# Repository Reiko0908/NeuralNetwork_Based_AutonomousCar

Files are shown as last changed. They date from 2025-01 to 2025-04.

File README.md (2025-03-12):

# NeuralNetwork_Based_AutonomousCar

## Project Overview
This project focuses on developing an autonomous car system powered by neural networks (NN). Inspired by the design architecture of micromouse, the car is designed to navigate autonomously using deep learning techniques. The project leverages deep learning and neural network models to enable the autonomous functionalities of the car. The neural network processes real-world sensor data to make real-time decisions for the car's navigation. The project timeline is divided into several stages:
1. **Concept Development**: Initial phase where the concept was developed.
2. **Gamepad PCB Design**: Creation of the gamepad hardware to control the car.
3. **Autonomous Car Design**: Currently in progress, focusing on the car's hardware and software integration.
4. **Neural Network Training**: Future phase where the model will be trained.
5. **Documentation**: Final phase to document the project.

## Software Architecture
- **Data Collection**: Using the gamepad (now replaced by computer control) to navigate the car in a physical map with walls. The sensors collect data and transmit it to the ESP32-S3 on the computer.
- **Machine Learning Training**: Utilizing Python and TensorFlow to train the neural network model.
- **Deployment**: Importing the trained model configurations to the car for autonomous navigation.

## Hardware

### Car Hardware
- **ESP32-S3 Super Mini**: Main microcontroller used in the car.
- **GY87 9-DOF IMU**: Inertial measurement unit for orientation and motion sensing.
- **5 VL53L0X Sensors**: Distance measurement sensors for mapping the environment.
- **L293DD Motor Driver**: Controls the motors of the car.
- **GA12 N20 Motor**: Motor with a step-up gearbox of 56:16 for movement.
- **2S Lipo Battery**

### Gamepad Hardware
- **Joysticks**
- **MPU6050 6-DOF IMU**
- **ESP32-S3 N16R8**
- **ST7789 LCD TFT SPI Screen**
- **IP5306 for Power Management**
- **Low Profile Switches**
- **Single-cell 18650 Battery**
- **Additional Buttons and Pin Headers**

## Machine Learning Training Procedure
1. **Collecting Data**: Create a physical map with walls and use the gamepad (now our computer) to control the car. The 5 VL53L0X sensors onboard will collect map data, transmit them to the ESP on the computer.
2. **Training the Model**: Use Python with TensorFlow library to train the neural network model.
3. **Deployment**: Import the trained model configurations to the car and let it navigate autonomously.

### Milestone Pictures
- **Micromouse Design Inspiration**
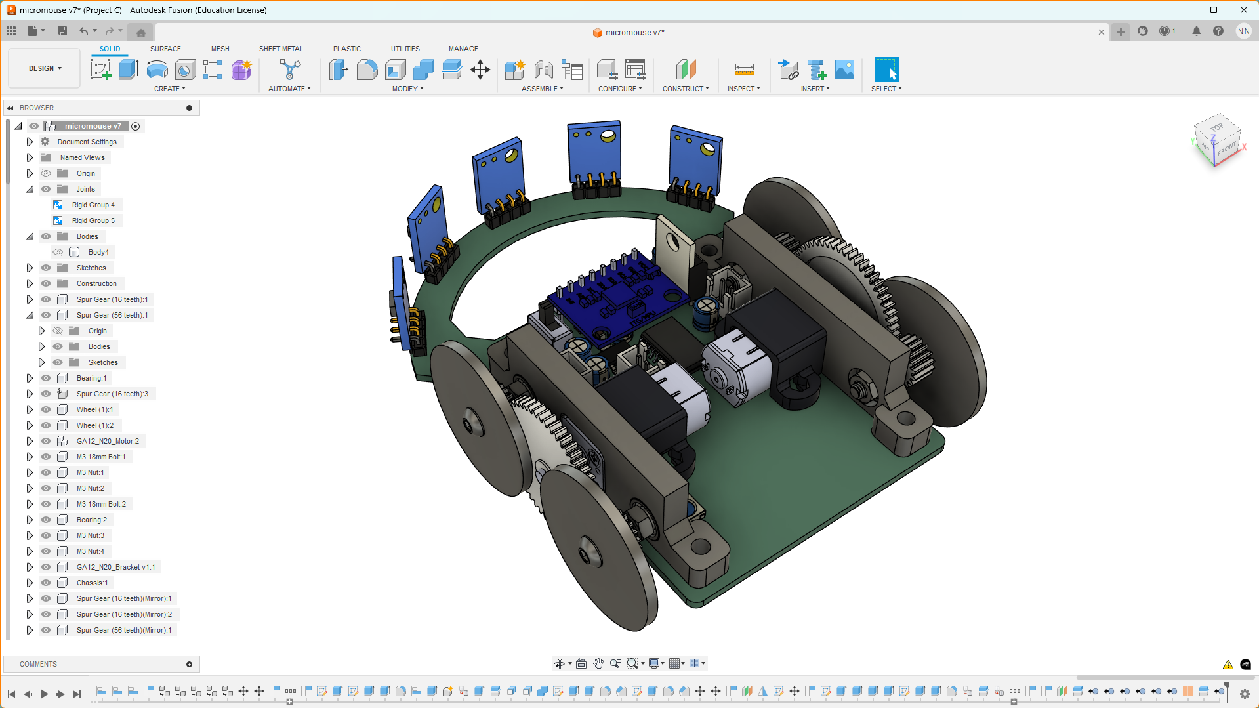
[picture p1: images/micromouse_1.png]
Micromouse 1
  
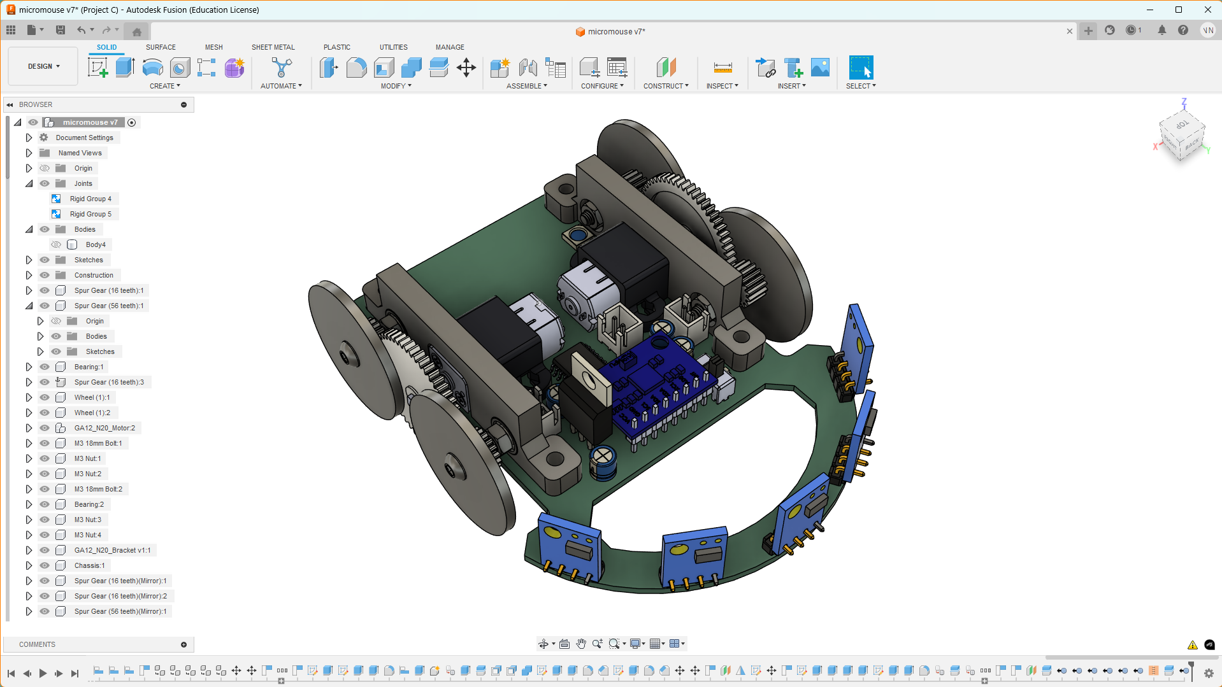
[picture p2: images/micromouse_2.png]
Micromouse 2
  
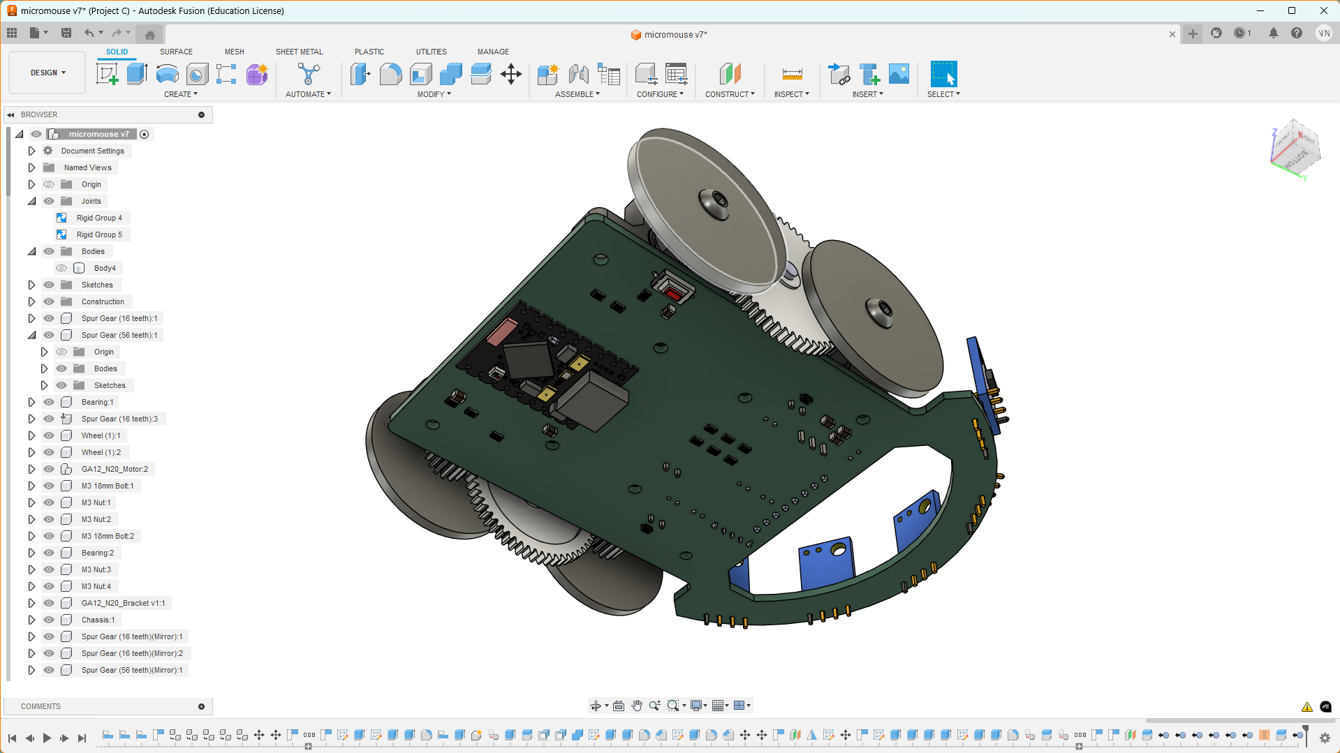
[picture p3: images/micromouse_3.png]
Micromouse 3
  
- **Gamepad PCB**
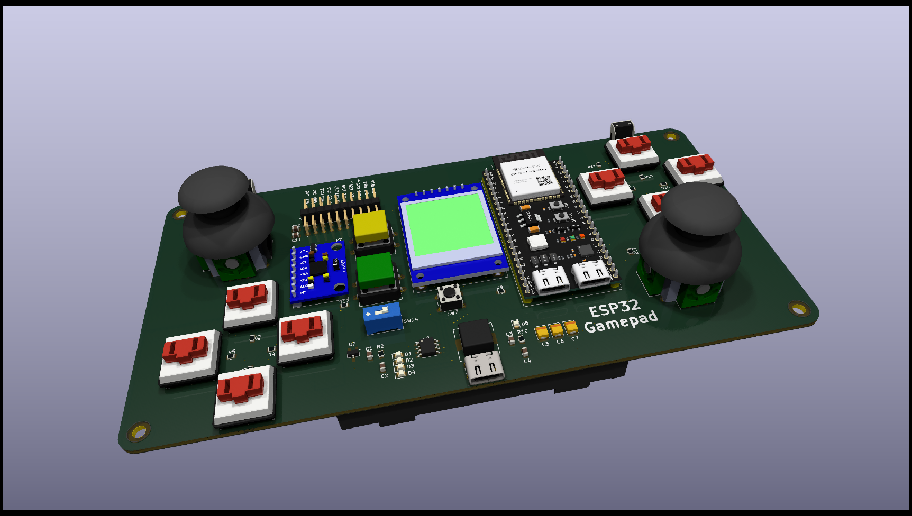
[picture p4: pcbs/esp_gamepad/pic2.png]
Gamepad Pic 2
  
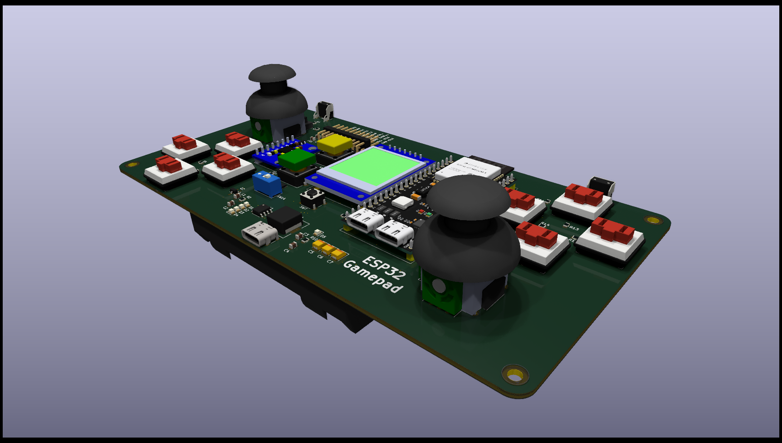
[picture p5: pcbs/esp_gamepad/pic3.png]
Gamepad Pic 3
  
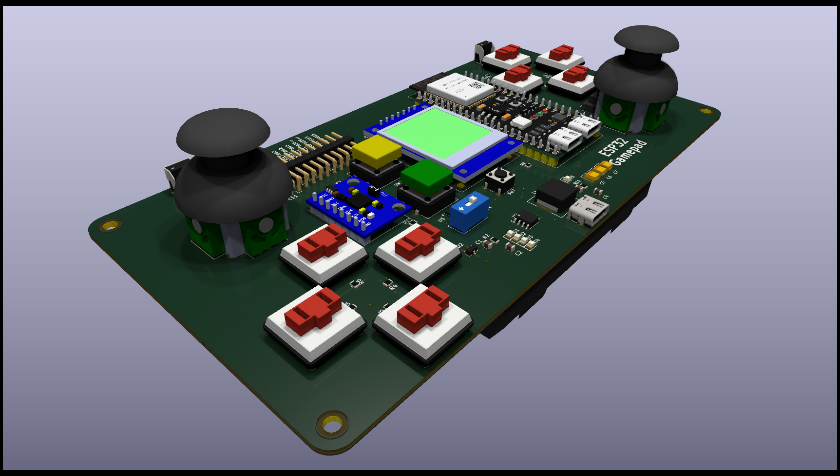
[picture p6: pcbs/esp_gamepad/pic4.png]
Gamepad Pic 4
  
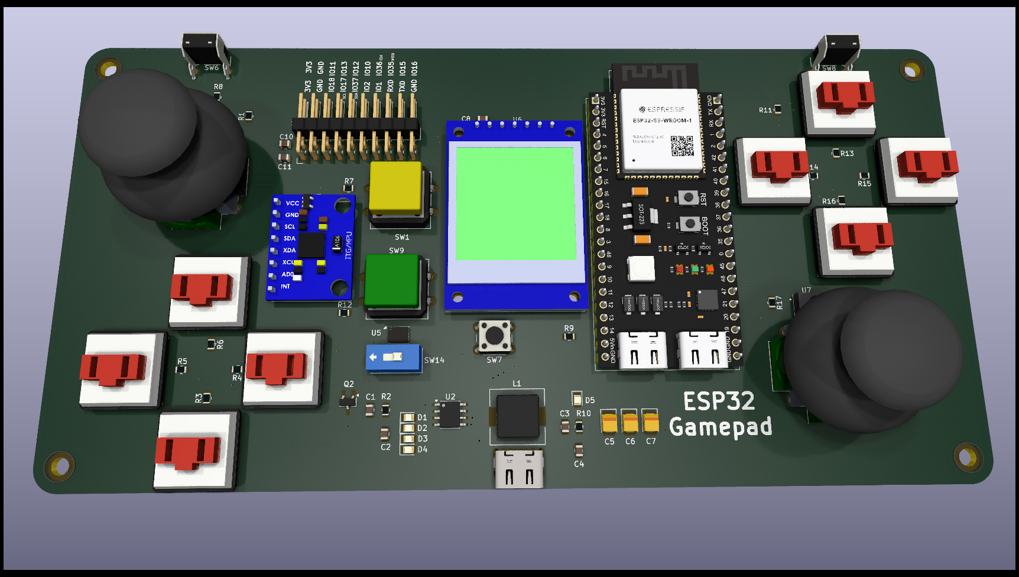
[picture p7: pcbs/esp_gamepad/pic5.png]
Gamepad Pic 5
  

## Additional Information
The gamepad PCB encountered a hardware issue that cannot be fixed in time. As a workaround, we will use an external ESP32-S3 connected to the computer to control the car via BLE. We will continue to develop and improve the project.

---

*Author: pacman314159*

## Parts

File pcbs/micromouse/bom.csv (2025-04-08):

Reference | Value | Datasheet | Footprint | Qty | DNP
BT1 | Lipo 2S | ~ | XH_2p54:2P_male | 1
C1,C2 | 100uF | ~ | Capacitor_SMD:C_0805_2012Metric_Pad1.18x1.45mm_HandSolder | 2
C3,C4,C8,C9,C14,C15 | 0.1uF | ~ | -- mixed values -- | 6
C5,C6,C7,C10,C11,C16,C17 | 10uF | ~ | -- mixed values -- | 7
C12,C13 | 470nF | ~ | Capacitor_THT:CP_Radial_D5.0mm_P2.00mm | 2
D1 | LED | ~ | LED_SMD:LED_0805_2012Metric_Pad1.15x1.40mm_HandSolder | 1
D2,D4 | 1N5819 | http://www.vishay.com/docs/88525/1n5817.pdf | Diode_SMD:D_SOD-323F | 2
D3 | WS2812B | https://cdn-shop.adafruit.com/datasheets/WS2812B.pdf | LED_SMD:LED_WS2812B_PLCC4_5.0x5.0mm_P3.2mm | 1
M1,M2 | GA12_N20 | ~ | XH_2p54:2P_male | 2
R1 | R | ~ | Resistor_SMD:R_0805_2012Metric_Pad1.20x1.40mm_HandSolder | 1
R2,R4,R5,R6,R7,R8,R9,R10,R11,R12,R13 | 10K | ~ | Resistor_SMD:R_0805_2012Metric_Pad1.20x1.40mm_HandSolder | 11
R3 | 6K2 | ~ | Resistor_SMD:R_0805_2012Metric_Pad1.20x1.40mm_HandSolder | 1
SW1 | SW_DPDT_x2 | ~ | SW_SS12D07VG4:SW_SS12D07VG4 | 1
SW2 | SW_Push | ~ | Button_Switch_SMD:SW_SPST_CK_RS282G05A3 | 1
U1,U4,U5,U6,U7,U8,U9,U10 | ~ |  | -- mixed values -- | 8
U2 | L7806 | http://www.st.com/content/ccc/resource/technical/document/datasheet/41/4f/b3/b0/12/d4/47/88/CD00000444.pdf/files/CD00000444.pdf/jcr:content/translations/en.CD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 | Package_TO_SOT_THT:TO-220-3_Vertical | 1
U3 | AMS1117-5.0 | http://www.advanced-monolithic.com/pdf/ds1117.pdf | Package_TO_SOT_SMD:SOT-223-3_TabPin2 | 1

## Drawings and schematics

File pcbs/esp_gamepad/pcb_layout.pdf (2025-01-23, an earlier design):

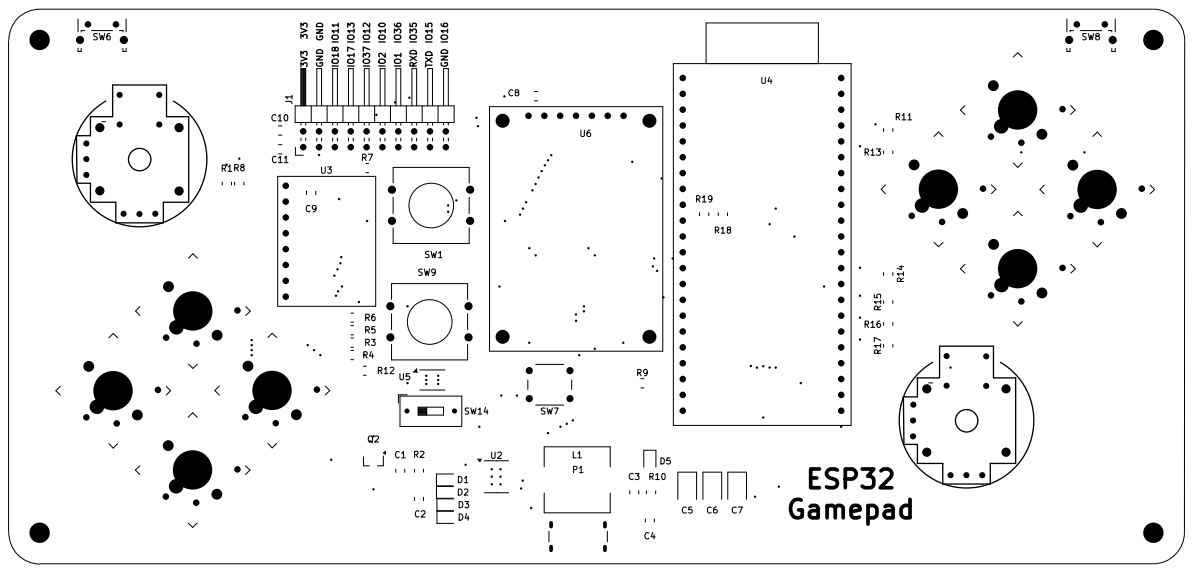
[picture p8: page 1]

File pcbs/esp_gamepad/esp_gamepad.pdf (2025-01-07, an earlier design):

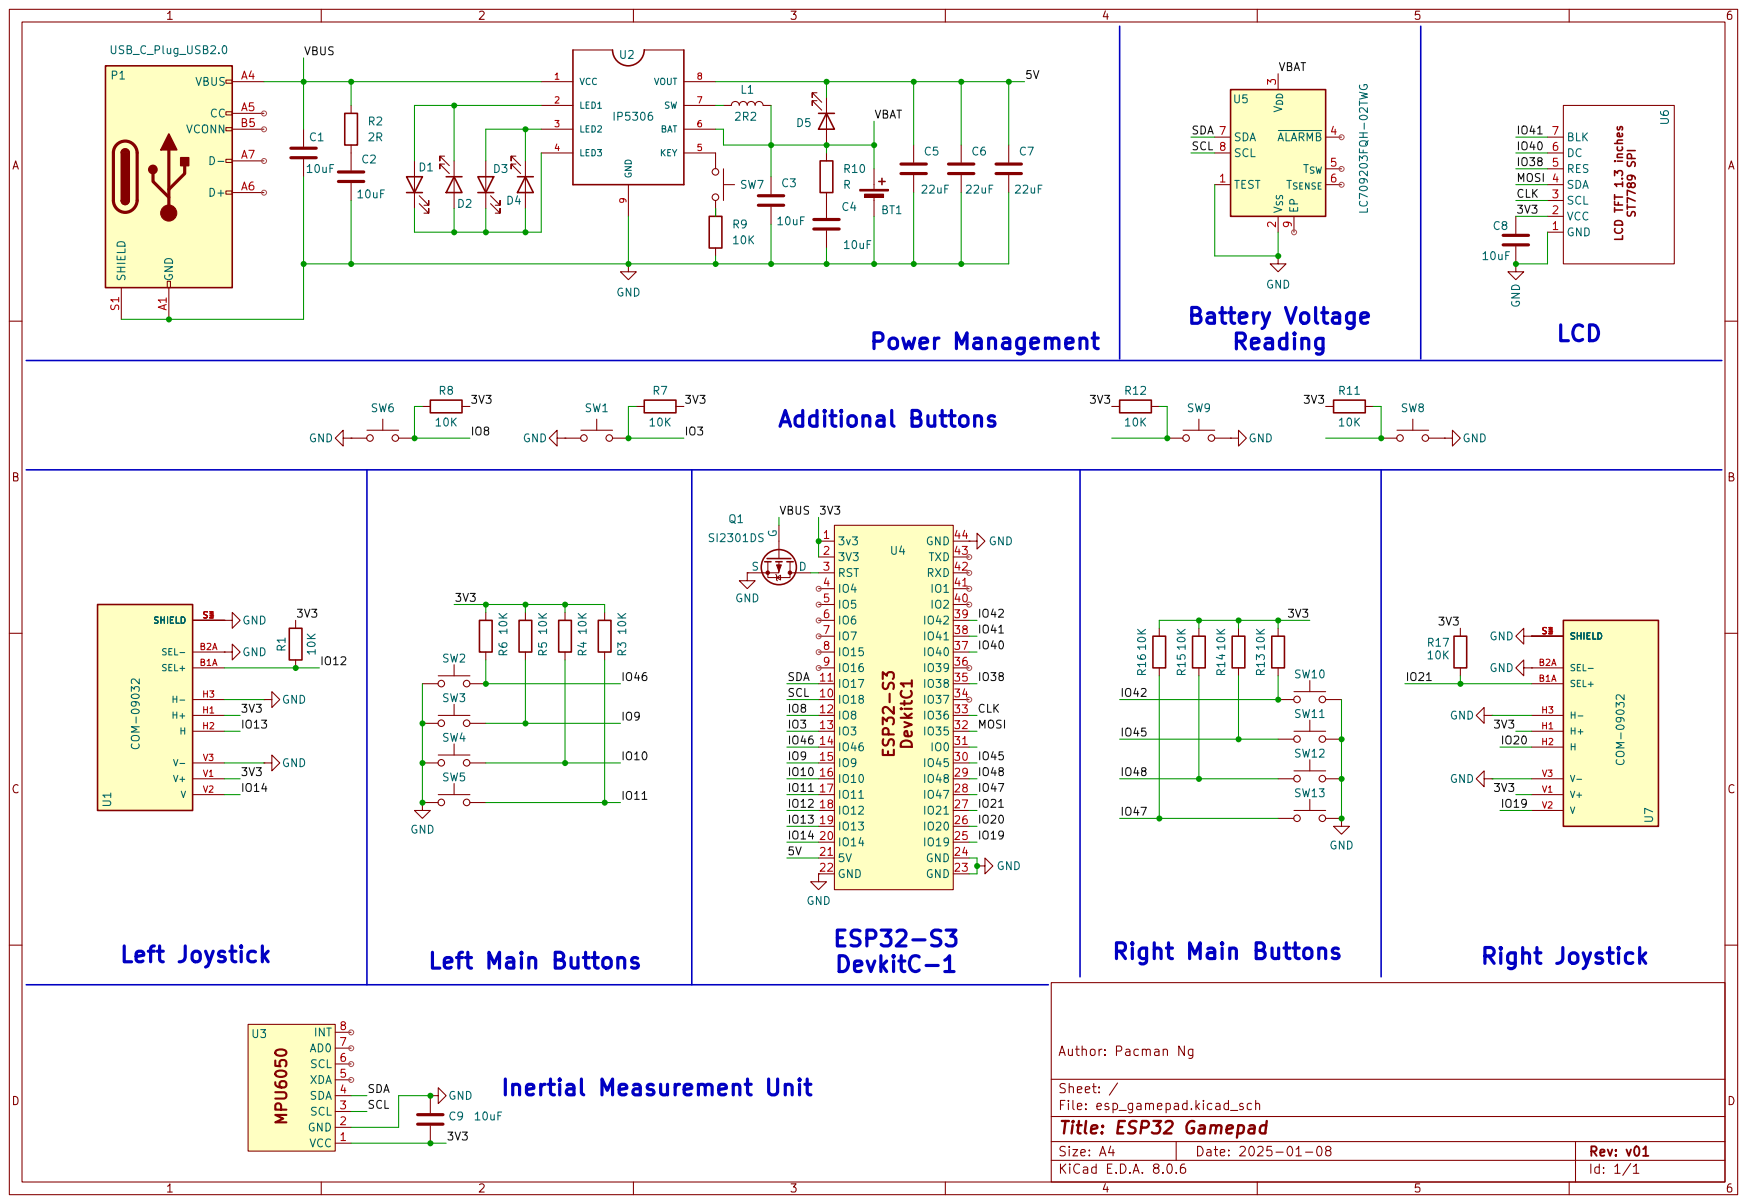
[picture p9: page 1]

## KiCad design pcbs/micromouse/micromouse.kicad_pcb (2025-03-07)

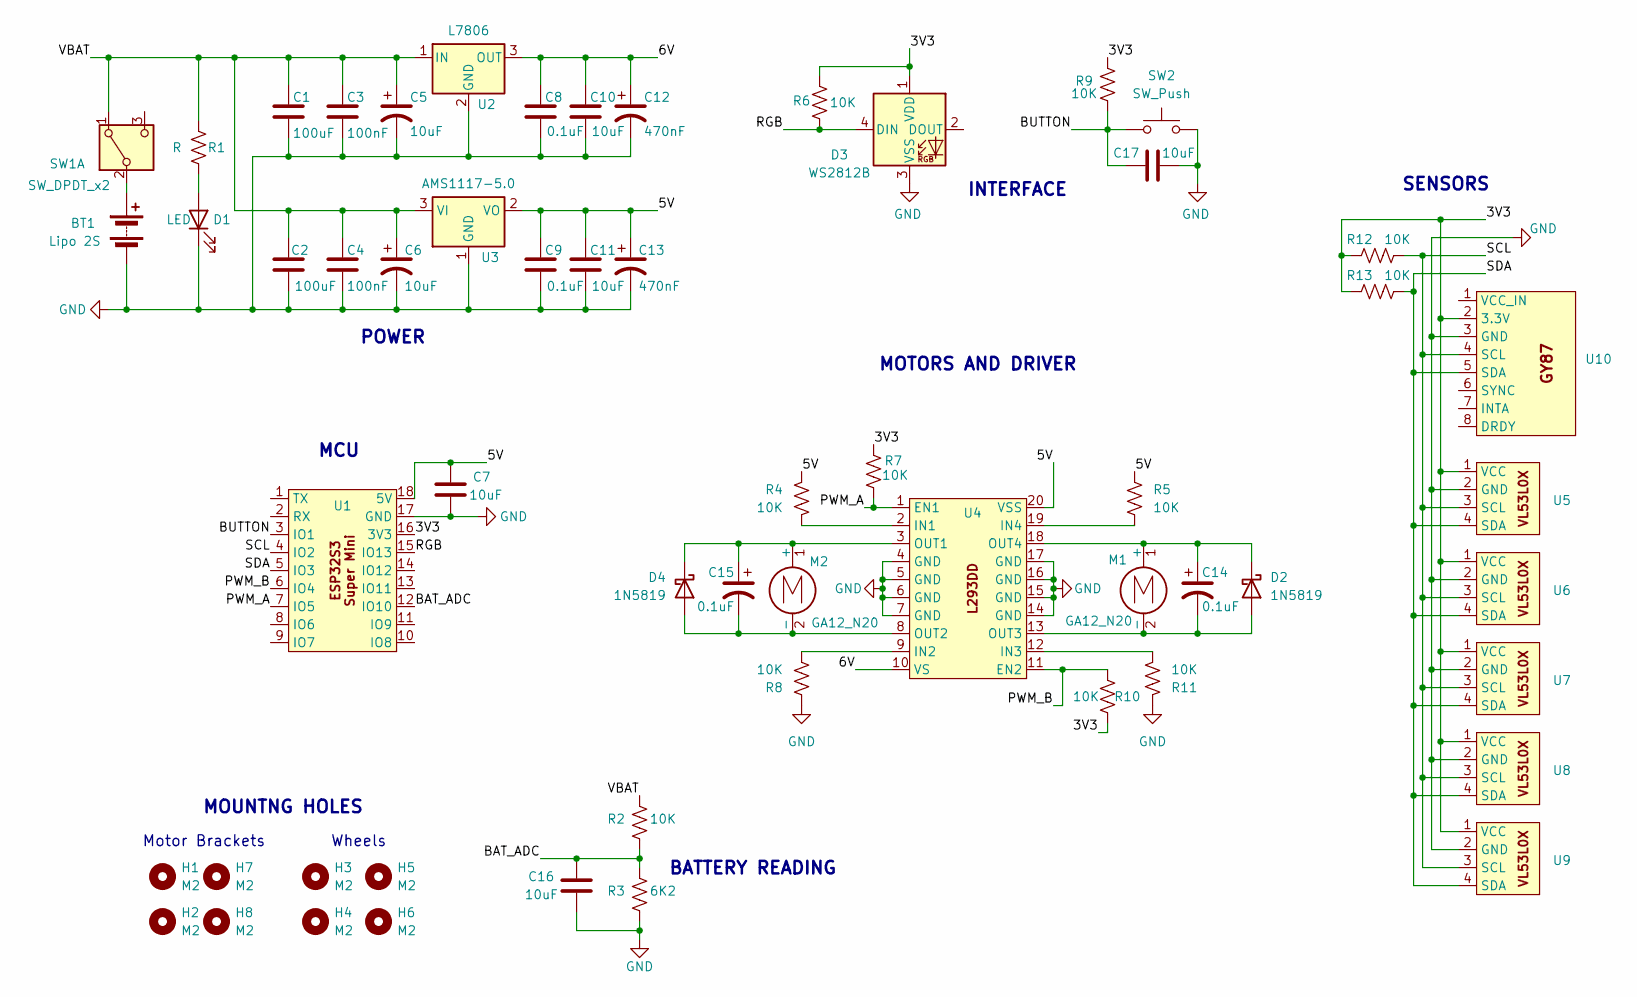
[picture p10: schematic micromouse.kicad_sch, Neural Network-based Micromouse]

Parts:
BT1: Lipo 2S; 2P_male
C1, C2: 100uF; C_0805_2012Metric_Pad1.18x1.45mm_HandSolder
C3, C4: 100nF; C_0805_2012Metric_Pad1.18x1.45mm_HandSolder
C5, C6: 10uF; CP_Radial_D5.0mm_P2.00mm
C7, C10, C11, C16, C17: 10uF; C_0805_2012Metric_Pad1.18x1.45mm_HandSolder
C8, C9: 0.1uF; C_0805_2012Metric_Pad1.18x1.45mm_HandSolder
C12, C13: 470nF; CP_Radial_D5.0mm_P2.00mm
C14, C15: 0.1uF; CP_Radial_D5.0mm_P2.00mm
D1: LED; LED_0805_2012Metric_Pad1.15x1.40mm_HandSolder
D2, D4: 1N5819; D_SOD-323F
D3: WS2812B; LED_WS2812B_PLCC4_5.0x5.0mm_P3.2mm
H1, H2, H3, H4, H5, H6, H7, H8: M2; MountingHole_2.2mm_M2
M1, M2: GA12_N20; 2P_male
R1: R; R_0805_2012Metric_Pad1.20x1.40mm_HandSolder
R2, R4, R5, R6, R7, R8, R9, R10, R11, R12, R13: 10K; R_0805_2012Metric_Pad1.20x1.40mm_HandSolder
R3: 6K2; R_0805_2012Metric_Pad1.20x1.40mm_HandSolder
SW1: SW_DPDT_x2; SW_SS12D07VG4
SW2: SW_Push; SW_SPST_CK_RS282G05A3
U1: esp32s3_super_mini
U2: L7806; TO-220-3_Vertical
U3: AMS1117-5.0; SOT-223-3_TabPin2
U4: SOP-20_7.5x12.8mm_P1.27mm
U5, U6, U7, U8, U9: VL53L0X_vertical
U10: GY87

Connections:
/3V3: D3.1 (VDD), R6.2, R7.2, R9.2, R10.2, R12.1, R13.1, U1.16 (3V3), U5.1 (VCC), U6.1 (VCC), U7.1 (VCC), U8.1 (VCC), U9.1 (VCC), U10.2 (3.3V)
/5V: C7.1, C9.1, C11.1, C13.1, R4.1, R5.1, U1.18 (5V), U3.2 (VO), U4.20 (VSS)
/6V: C8.1, C10.1, C12.1, U2.3 (OUT), U4.10 (VS)
/BAT_ADC: C16.1, R2.1, R3.2, U1.12 (IO10)
/BUTTON: C17.1, R9.1, SW2.1, U1.3 (IO1)
/PWM_A: R7.1, U1.7 (IO5), U4.1 (EN1)
/PWM_B: R10.1, U1.6 (IO4), U4.11 (EN2)
/RGB: D3.4 (DIN), R6.1, U1.15 (IO13)
/SCL: R12.2, U1.4 (IO2), U5.3 (SCL), U6.3 (SCL), U7.3 (SCL), U8.3 (SCL), U9.3 (SCL), U10.4 (SCL)
/SDA: R13.2, U1.5 (IO3), U5.4 (SDA), U6.4 (SDA), U7.4 (SDA), U8.4 (SDA), U9.4 (SDA), U10.5 (SDA)
/VBAT: C1.1, C2.1, C3.1, C4.1, C5.1, C6.1, R1.1, R2.2, SW1.1 (A), U2.1 (IN), U3.3 (VI)
GND: BT1.2 (-), C1.2, C2.2, C3.2, C4.2, C5.2, C6.2, C7.2, C8.2, C9.2, C10.2, C11.2, C12.2, C13.2, C16.2, C17.2, D1.1 (K), D3.3 (VSS), R3.1, R8.1, R11.1, SW2.2, U1.17 (GND), U2.2 (GND), U3.1 (GND), U4.4 (GND), U4.5 (GND), U4.6 (GND), U4.7 (GND), U4.14 (GND), U4.15 (GND), U4.16 (GND), U4.17 (GND), U5.2 (GND), U6.2 (GND), U7.2 (GND), U8.2 (GND), U9.2 (GND), U10.3 (GND)
unnamed: BT1.1 (+), SW1.2 (B)
unnamed: D1.2 (A), R1.2
unnamed: C14.2, D2.2 (A), M1.2 (-), U4.13 (OUT3)
unnamed: C14.1, D2.1 (K), M1.1 (+), U4.18 (OUT4)
unnamed: C15.2, D4.2 (A), M2.2 (-), U4.8 (OUT2)
unnamed: C15.1, D4.1 (K), M2.1 (+), U4.3 (OUT1)
unnamed: R4.2, U4.2 (IN1)
unnamed: R8.2, U4.9 (IN2)
unnamed: R11.2, U4.12 (IN3)
unnamed: R5.2, U4.19 (IN4)

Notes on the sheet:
MCU
MOUNTNG HOLES
POWER
BATTERY READING
Wheels
Motor Brackets
SENSORS
MOTORS AND DRIVER
INTERFACE

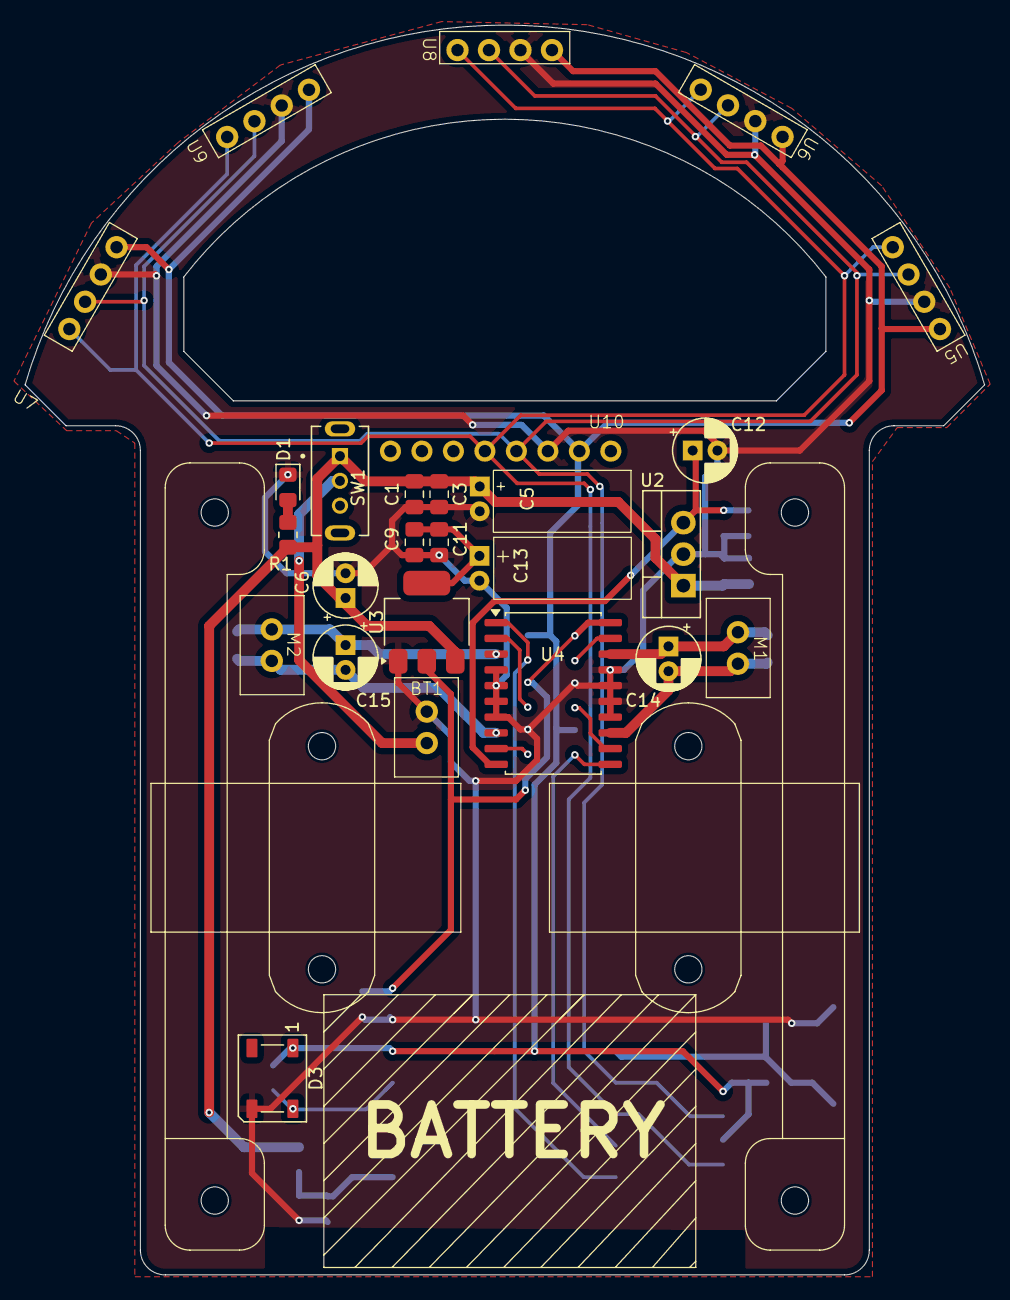
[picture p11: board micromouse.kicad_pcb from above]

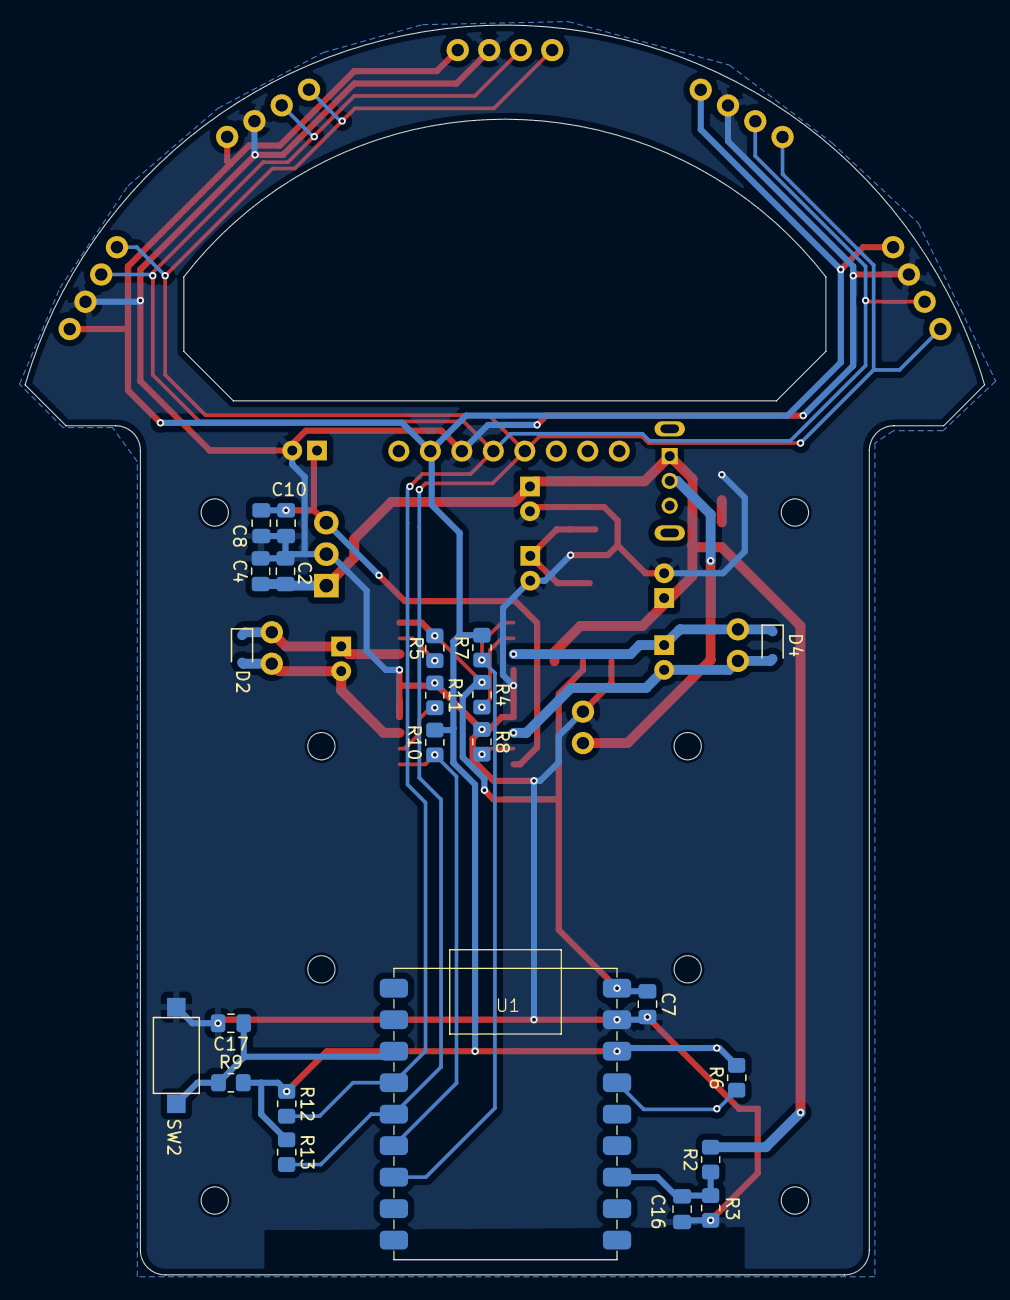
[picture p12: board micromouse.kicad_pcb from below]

Board: 2 copper layers, 77.4 x 100.8 mm, 57 parts (23 on the bottom side), 22 nets.

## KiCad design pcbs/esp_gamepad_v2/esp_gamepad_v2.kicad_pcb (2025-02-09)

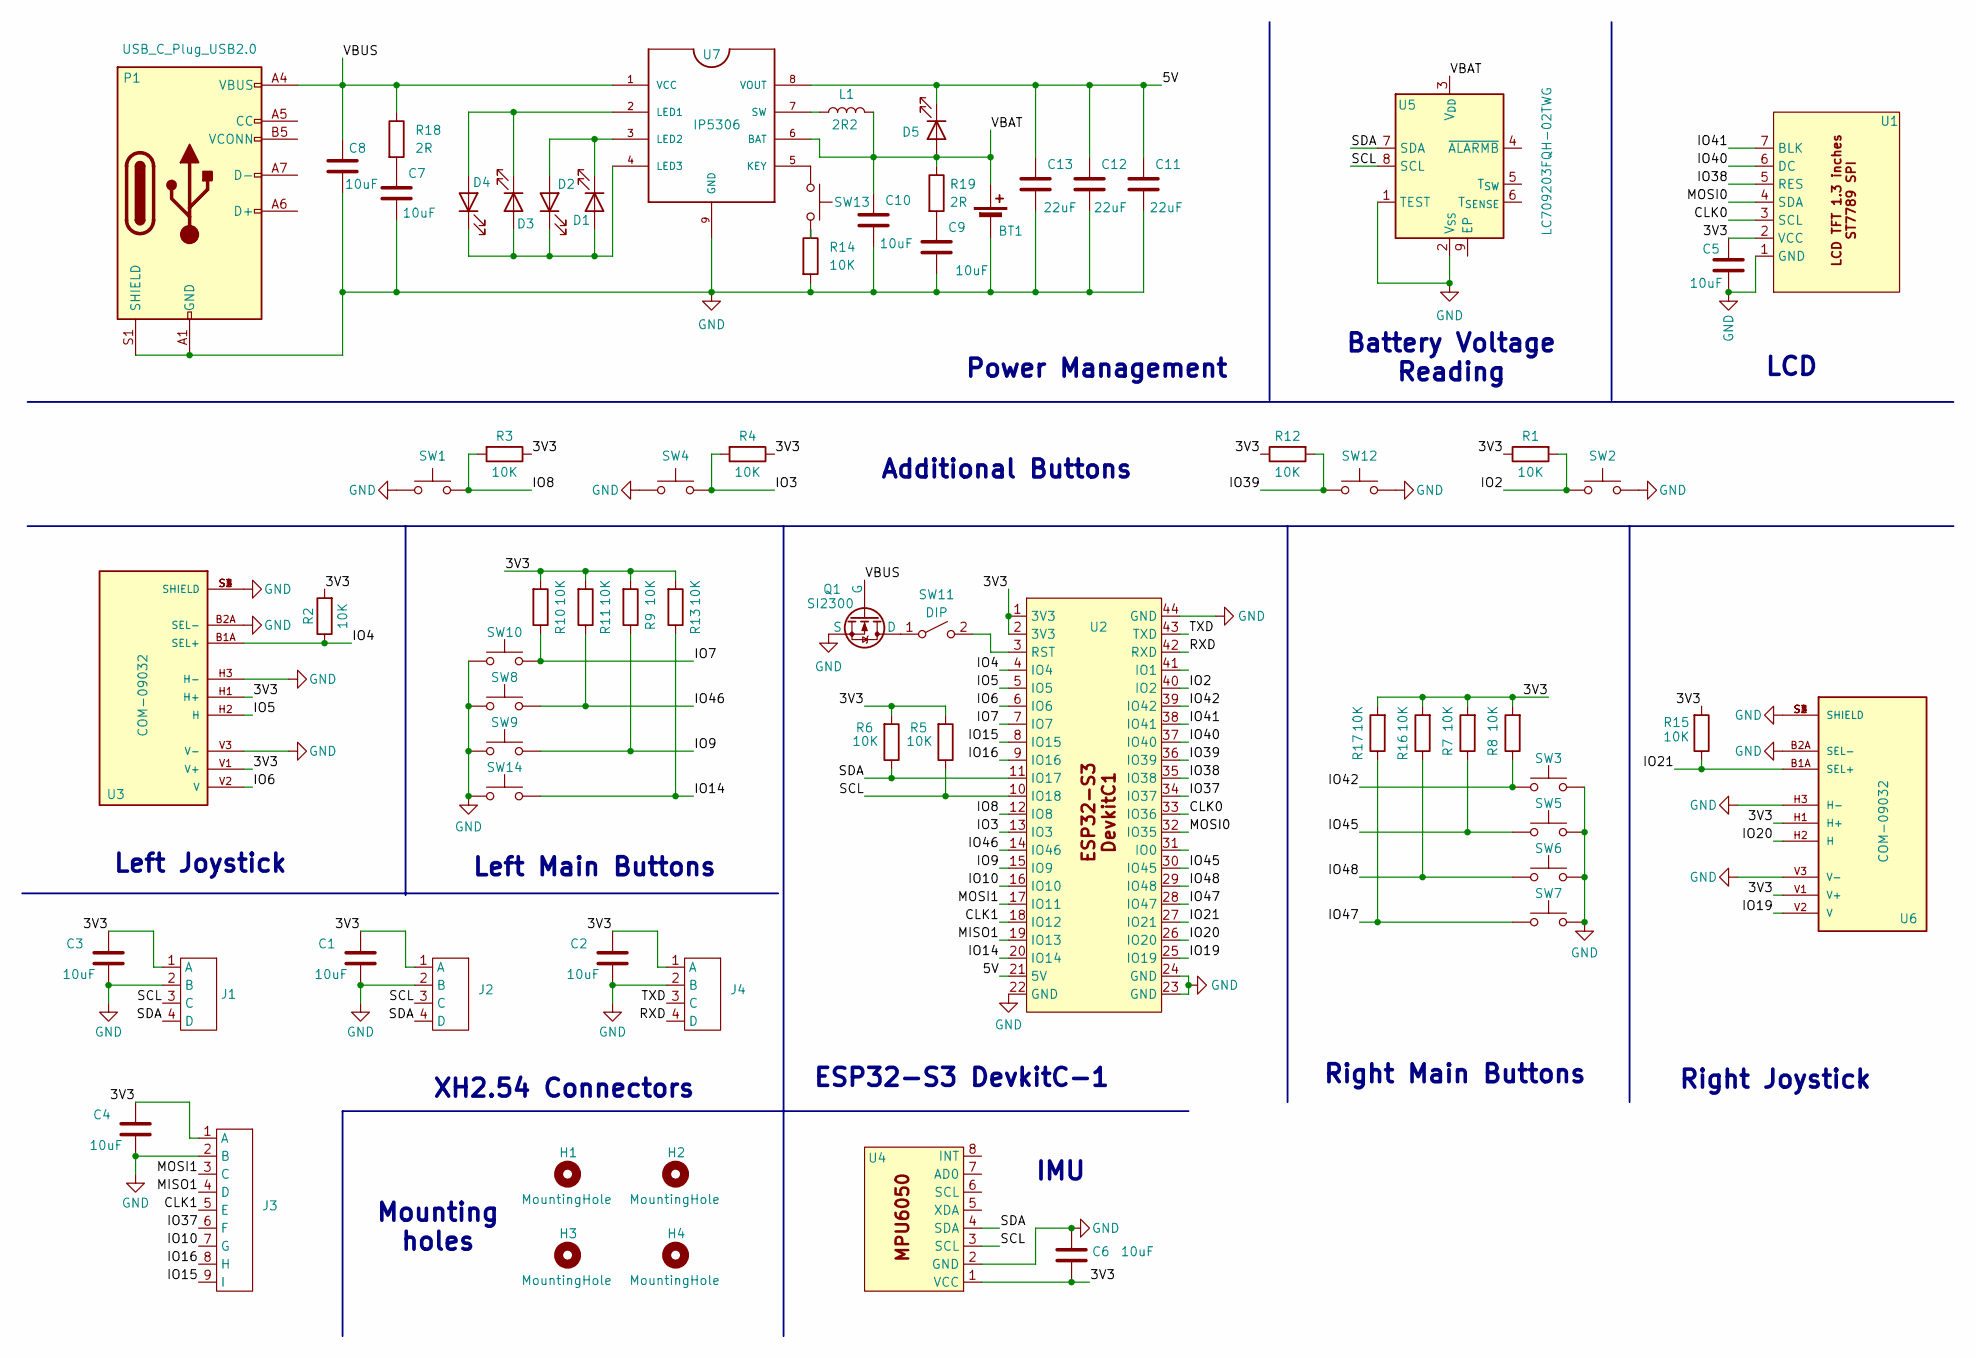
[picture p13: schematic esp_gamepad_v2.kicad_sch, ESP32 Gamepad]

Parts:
BT1: Battery_Cell; BatteryHolder_Keystone_1042_1x18650
C1, C2, C3, C4, C5, C6, C7, C8, C9, C10: 10uF; C_0805_2012Metric
C11, C12, C13: 22uF; CP_EIA-3528-15_AVX-H_Pad1.50x2.35mm_HandSolder
D1, D2, D3, D4, D5: LED; LED_0805_2012Metric
H1, H2, H3, H4: MountingHole; MountingHole_3.2mm_M3_Pad
J1, J2, J4: XH_2p54_4P_male
J3: XH_2p54_9P_male
L1: 2R2; L_10.4x10.4_H4.8
P1: USB_C_Plug_USB2.0; USB_C_Receptacle_GCT_USB4125-xx-x-0190_6P_TopMnt_Horizontal
Q1: SI2300; SOT-23_Handsoldering
R1, R2, R3, R4, R5, R6, R7, R8, R9, R10, R11, R12, R13, R14, R15, R16, R17: 10K; R_0805_2012Metric
R18, R19: 2R; R_0805_2012Metric
SW1, SW2: SW_Push; SW_Tactile_SPST_Angled_PTS645Vx31-2LFS
SW3, SW5, SW6, SW7, SW8, SW9, SW10, SW14: SW_Push; SW_MX_LowProfile_Kailh_Choc_V1V2_THT_Hybrid
SW4, SW12: SW_Push; SW_PUSH-12mm
SW11: DIP; SW_DIP_SPSTx01_Slide_9.78x4.72mm_W7.62mm_P2.54mm
SW13: SW_Push; SW_PUSH_6mm
U1: LCD_TFT_1.3_inches_ST7789
U2: ESP32_S3_DevkitC1
U3, U6: COM-09032; PS4_joystick; PARTREV N/A
U4: MPU6050
U5: LC709203FQH-02TWG; WDFN-8-1EP_4x3mm_P0.65mm_EP2.4x1.8mm_ThermalVias
U7: IP5306; SOIC-8-1EP_3.9x4.9mm_P1.27mm_EP2.41x3.3mm_ThermalVias

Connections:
/3V3: C1.1, C2.1, C3.1, C4.1, C5.1, C6.2, J1.1 (A), J2.1 (A), J3.1 (A), J4.1 (A), R1.1, R2.2, R3.1, R4.1, R5.2, R6.2, R7.2, R8.2, R9.2, R10.2, R11.2, R12.1, R13.2, R15.2, R16.2, R17.2, U1.2 (VCC), U2.1 (3V3), U2.2 (3V3), U3.H1 (H+), U3.V1 (V+), U4.1 (VCC), U6.H1 (H+), U6.V1 (V+)
/5V: C11.1, C12.1, C13.1, D5.1 (K), U2.21 (5V), U7.8 (VOUT)
/CLK0: U1.3 (SCL), U2.33 (IO36)
/CLK1: J3.5 (E), U2.18 (IO12)
/IO2: R1.2, SW2.2, U2.40 (IO2)
/IO3: R4.2, SW4.2, U2.13 (IO3)
/IO4: R2.1, U2.4 (IO4), U3.B1A (SEL+)
/IO5: U2.5 (IO5), U3.H2 (H)
/IO6: U2.6 (IO6), U3.V2 (V)
/IO7: R10.1, SW10.1, U2.7 (IO7)
/IO8: R3.2, SW1.2, U2.12 (IO8)
/IO9: R9.1, SW9.1, U2.15 (IO9)
/IO10: J3.7 (G), U2.16 (IO10)
/IO14: R13.1, SW14.1, U2.20 (IO14)
/IO15: J3.9 (I), U2.8 (IO15)
/IO16: J3.8 (H), U2.9 (IO16)
/IO19: U2.25 (IO19), U6.V2 (V)
/IO20: U2.26 (IO20), U6.H2 (H)
/IO21: R15.1, U2.27 (IO21), U6.B1A (SEL+)
/IO37: J3.6 (F), U2.34 (IO37)
/IO38: U1.5 (RES), U2.35 (IO38)
/IO39: R12.2, SW12.2, U2.36 (IO39)
/IO40: U1.6 (DC), U2.37 (IO40)
/IO41: U1.7 (BLK), U2.38 (IO41)
/IO42: R8.1, SW3.1, U2.39 (IO42)
/IO45: R7.1, SW5.1, U2.30 (IO45)
/IO46: R11.1, SW8.1, U2.14 (IO46)
/IO47: R17.1, SW7.1, U2.28 (IO47)
/IO48: R16.1, SW6.1, U2.29 (IO48)
/MISO1: J3.4 (D), U2.19 (IO13)
/MOSI0: U1.4 (SDA), U2.32 (IO35)
/MOSI1: J3.3 (C), U2.17 (IO11)
/RXD: J4.4 (D), U2.42 (RXD)
/SCL: J1.3 (C), J2.3 (C), R5.1, U2.10 (IO18), U4.3 (SCL), U5.8 (SCL)
/SDA: J1.4 (D), J2.4 (D), R6.1, U2.11 (IO17), U4.4 (SDA), U5.7 (SDA)
/TXD: J4.3 (C), U2.43 (TXD)
/VBAT: BT1.1 (+), C10.1, D5.2 (A), L1.2, R19.1, U5.3 (V_{DD}), U7.6 (BAT)
/VBUS: C8.1, P1.A4 (VBUS), P1.A9 (VBUS), P1.B4 (VBUS), P1.B9 (VBUS), Q1.1 (G), R18.1, U7.1 (VCC)
GND: BT1.2 (-), C1.2, C2.2, C3.2, C4.2, C5.2, C6.1, C7.2, C8.2, C9.2, C10.2, C11.2, C12.2, C13.2, J1.2 (B), J2.2 (B), J3.2 (B), J4.2 (B), P1.A1 (GND), P1.A12 (GND), P1.B1 (GND), P1.B12 (GND), P1.S1 (SHIELD), Q1.2 (S), R14.2, SW1.1, SW2.1, SW3.2, SW4.1, SW5.2, SW6.2, SW7.2, SW8.2, SW9.2, SW10.2, SW12.1, SW14.2, U1.1 (GND), U2.22 (GND), U2.23 (GND), U2.24 (GND), U2.44 (GND), U3.B2A (SEL-), U3.H3 (H-), U3.S1 (SHIELD), U3.S2 (SHIELD), U3.S3 (SHIELD), U3.S4 (SHIELD), U3.V3 (V-), U4.2 (GND), U5.1 (TEST), U5.2 (V_{SS}), U6.B2A (SEL-), U6.H3 (H-), U6.S1 (SHIELD), U6.S2 (SHIELD), U6.S3 (SHIELD), U6.S4 (SHIELD), U6.V3 (V-), U7.9 (GND)
unnamed: C7.1, R18.2
unnamed: C9.1, R19.2
unnamed: D1.2 (A), D2.1 (K), D3.2 (A), D4.1 (K), U7.4 (LED3)
unnamed: D1.1 (K), D2.2 (A), U7.3 (LED2)
unnamed: D3.1 (K), D4.2 (A), U7.2 (LED1)
unnamed: Q1.3 (D), SW11.1 (A)
unnamed: R14.1, SW13.2
unnamed: SW11.2 (B), U2.3 (RST)
unnamed: SW13.1, U7.5 (KEY)
unnamed: L1.1, U7.7 (SW)

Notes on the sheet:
Left Main Buttons
XH2.54 Connectors
Mounting holes
Battery Voltage Reading
Power Management
IMU
Additional Buttons
ESP32-S3 DevkitC-1
Right Joystick
Left Joystick
LCD
Right Main Buttons

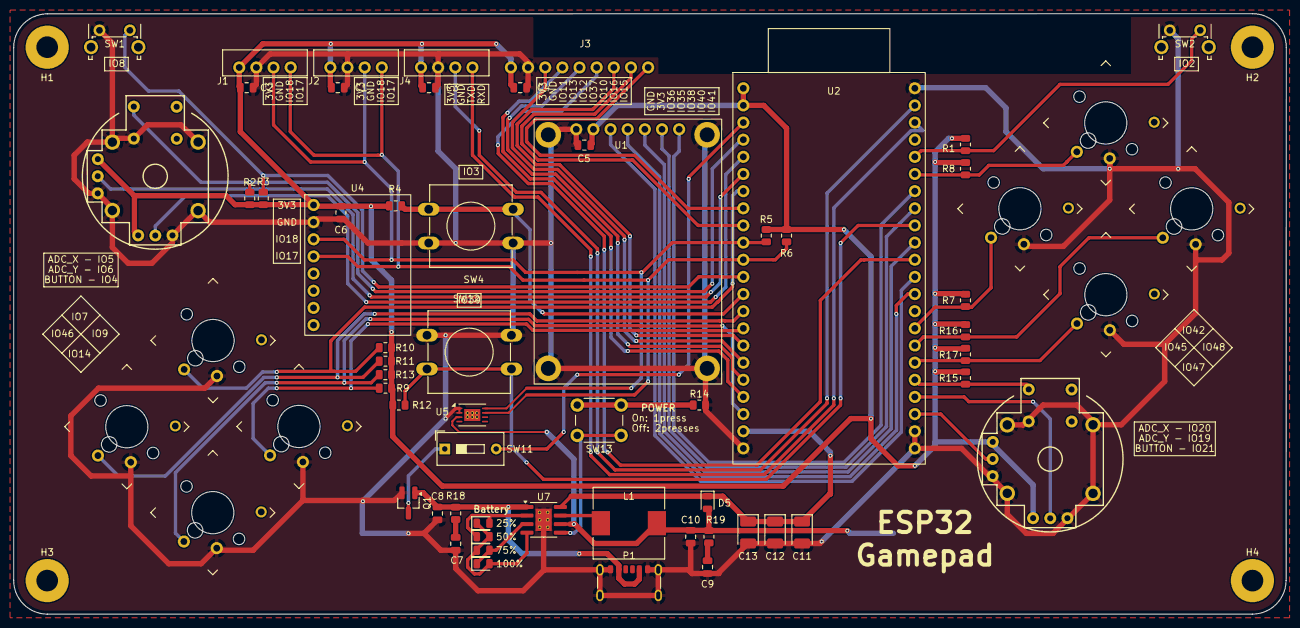
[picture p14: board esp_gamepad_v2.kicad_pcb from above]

Board: 2 copper layers, 188.5 x 88.9 mm, 70 parts (1 on the bottom side), 49 nets.

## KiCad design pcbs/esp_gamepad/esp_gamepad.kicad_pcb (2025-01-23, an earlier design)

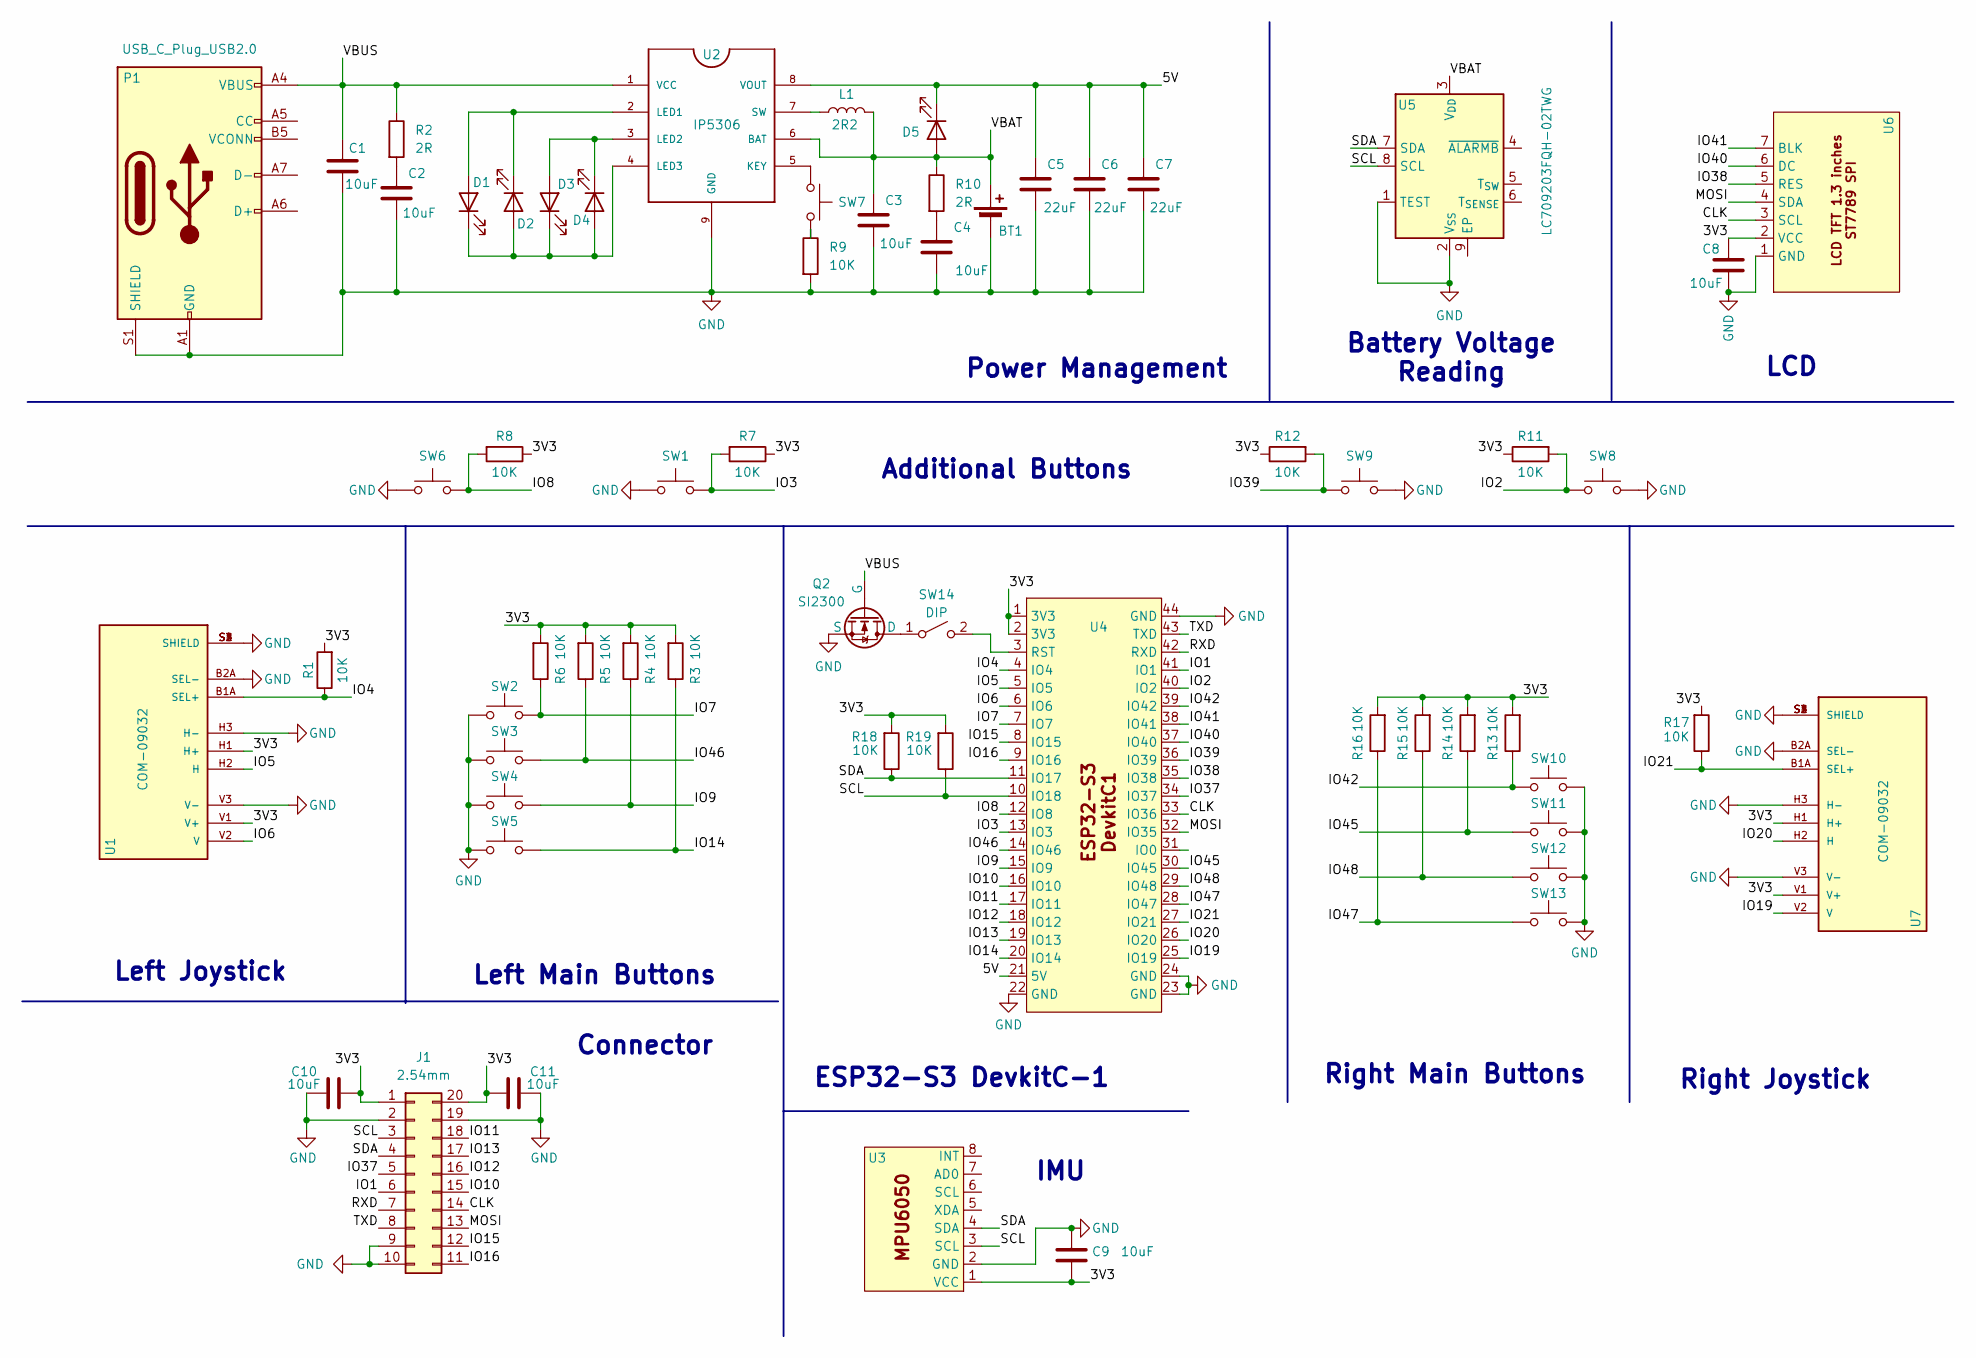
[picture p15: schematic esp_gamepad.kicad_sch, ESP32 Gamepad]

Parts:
BT1: Battery_Cell; BatteryHolder_Keystone_1042_1x18650
C1, C2, C3, C4, C8, C9, C10, C11: 10uF; C_0805_2012Metric
C5, C6, C7: 22uF; CP_EIA-3528-15_AVX-H_Pad1.50x2.35mm_HandSolder
D1, D2, D3, D4, D5: LED; LED_0805_2012Metric
J1: 2.54mm; PinHeader_2x10_P2.54mm_Horizontal
L1: 2R2; L_10.4x10.4_H4.8
P1: USB_C_Plug_USB2.0; USB_Type_C_6P
Q2: SI2300; SOT-23_Handsoldering
R1, R3, R4, R5, R6, R7, R8, R9, R11, R12, R13, R14, R15, R16, R17, R18, R19: 10K; R_0805_2012Metric
R2, R10: 2R; R_0805_2012Metric
SW1, SW9: SW_Push; SW_PUSH-12mm
SW2, SW3, SW4, SW5, SW10, SW11, SW12, SW13: SW_Push; SW_MX_LowProfile_Kailh_Choc_V1V2_THT_Hybrid
SW6, SW8: SW_Push; SW_Tactile_SPST_Angled_PTS645Vx31-2LFS
SW7: SW_Push; SW_PUSH_6mm
SW14: DIP; SW_DIP_SPSTx01_Slide_9.78x4.72mm_W7.62mm_P2.54mm
U1, U7: COM-09032; PS4_joystick; PARTREV N/A
U2: IP5306; SOIC-8-1EP_3.9x4.9mm_P1.27mm_EP2.41x3.3mm_ThermalVias
U3: MPU6050
U4: ESP32_S3_DevkitC1
U5: LC709203FQH-02TWG; WDFN-8-1EP_4x3mm_P0.65mm_EP2.4x1.8mm_ThermalVias
U6: LCD_TFT_1.3_inches_ST7789

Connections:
/3V3: C8.1, C9.2, C10.1, C11.1, J1.1, J1.20, R1.2, R3.2, R4.2, R5.2, R6.2, R7.1, R8.1, R11.1, R12.1, R13.2, R14.2, R15.2, R16.2, R17.2, R18.2, R19.2, U1.H1 (H+), U1.V1 (V+), U3.1 (VCC), U4.1 (3V3), U4.2 (3V3), U6.2 (VCC), U7.H1 (H+), U7.V1 (V+)
/5V: C5.1, C6.1, C7.1, D5.1 (K), U2.8 (VOUT), U4.21 (5V)
/CLK: J1.14, U4.33 (IO36), U6.3 (SCL)
/IO1: J1.6, U4.41 (IO1)
/IO2: R11.2, SW8.2, U4.40 (IO2)
/IO3: R7.2, SW1.2, U4.13 (IO3)
/IO4: R1.1, U1.B1A (SEL+), U4.4 (IO4)
/IO5: U1.H2 (H), U4.5 (IO5)
/IO6: U1.V2 (V), U4.6 (IO6)
/IO7: R6.1, SW2.1, U4.7 (IO7)
/IO8: R8.2, SW6.2, U4.12 (IO8)
/IO9: R4.1, SW4.1, U4.15 (IO9)
/IO10: J1.15, U4.16 (IO10)
/IO11: J1.18, U4.17 (IO11)
/IO12: J1.16, U4.18 (IO12)
/IO13: J1.17, U4.19 (IO13)
/IO14: R3.1, SW5.1, U4.20 (IO14)
/IO15: J1.12, U4.8 (IO15)
/IO16: J1.11, U4.9 (IO16)
/IO19: U4.25 (IO19), U7.V2 (V)
/IO20: U4.26 (IO20), U7.H2 (H)
/IO21: R17.1, U4.27 (IO21), U7.B1A (SEL+)
/IO37: J1.5, U4.34 (IO37)
/IO38: U4.35 (IO38), U6.5 (RES)
/IO39: R12.2, SW9.2, U4.36 (IO39)
/IO40: U4.37 (IO40), U6.6 (DC)
/IO41: U4.38 (IO41), U6.7 (BLK)
/IO42: R13.1, SW10.1, U4.39 (IO42)
/IO45: R14.1, SW11.1, U4.30 (IO45)
/IO46: R5.1, SW3.1, U4.14 (IO46)
/IO47: R16.1, SW13.1, U4.28 (IO47)
/IO48: R15.1, SW12.1, U4.29 (IO48)
/MOSI: J1.13, U4.32 (IO35), U6.4 (SDA)
/RXD: J1.7, U4.42 (RXD)
/SCL: J1.3, R19.1, U3.3 (SCL), U4.10 (IO18), U5.8 (SCL)
/SDA: J1.4, R18.1, U3.4 (SDA), U4.11 (IO17), U5.7 (SDA)
/TXD: J1.8, U4.43 (TXD)
/VBAT: BT1.1 (+), C3.1, D5.2 (A), L1.2, R10.1, U2.6 (BAT), U5.3 (V_{DD})
/VBUS: C1.1, P1.A4 (VBUS), P1.A9 (VBUS), P1.B4 (VBUS), P1.B9 (VBUS), Q2.2 (G), R2.1, U2.1 (VCC)
GND: BT1.2 (-), C1.2, C2.2, C3.2, C4.2, C5.2, C6.2, C7.2, C8.2, C9.1, C10.2, C11.2, J1.2, J1.9, J1.10, J1.19, P1.A1 (GND), P1.A12 (GND), P1.B1 (GND), P1.B12 (GND), P1.S1 (SHIELD), Q2.3 (S), R9.2, SW1.1, SW2.2, SW3.2, SW4.2, SW5.2, SW6.1, SW8.1, SW9.1, SW10.2, SW11.2, SW12.2, SW13.2, U1.B2A (SEL-), U1.H3 (H-), U1.S1 (SHIELD), U1.S2 (SHIELD), U1.S3 (SHIELD), U1.S4 (SHIELD), U1.V3 (V-), U2.9 (GND), U3.2 (GND), U4.22 (GND), U4.23 (GND), U4.24 (GND), U4.44 (GND), U5.1 (TEST), U5.2 (V_{SS}), U6.1 (GND), U7.B2A (SEL-), U7.H3 (H-), U7.S1 (SHIELD), U7.S2 (SHIELD), U7.S3 (SHIELD), U7.S4 (SHIELD), U7.V3 (V-)
unnamed: C2.1, R2.2
unnamed: C4.1, R10.2
unnamed: D1.2 (A), D2.1 (K), U2.2 (LED1)
unnamed: D1.1 (K), D2.2 (A), D3.1 (K), D4.2 (A), U2.4 (LED3)
unnamed: D3.2 (A), D4.1 (K), U2.3 (LED2)
unnamed: Q2.1 (D), SW14.1 (A)
unnamed: R9.1, SW7.2
unnamed: SW14.2 (B), U4.3 (RST)
unnamed: SW7.1, U2.5 (KEY)
unnamed: L1.1, U2.7 (SW)

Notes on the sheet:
Left Main Buttons
Connector
Battery Voltage Reading
Power Management
IMU
Additional Buttons
ESP32-S3 DevkitC-1
Right Joystick
Left Joystick
LCD
Right Main Buttons

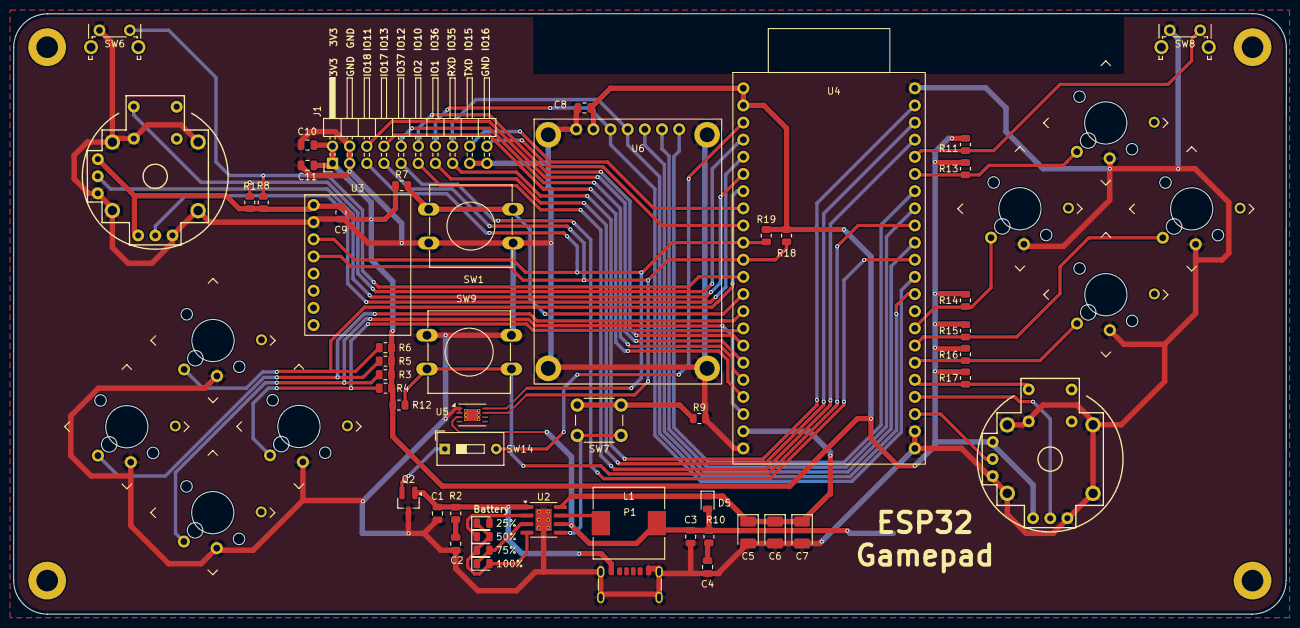
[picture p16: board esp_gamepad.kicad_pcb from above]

Board: 2 copper layers, 188.5 x 88.9 mm, 61 parts (1 on the bottom side), 50 nets.

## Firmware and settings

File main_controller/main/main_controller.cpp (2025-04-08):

#include <stdio.h>
#include "driver/gpio.h"
#include "driver/i2c.h"
#include "freertos/FreeRTOS.h"
#include "freertos/idf_additions.h"
#include "freertos/projdefs.h"
#include "freertos/task.h"
#include "esp_adc/adc_oneshot.h"
#include "freertos/semphr.h"

#include "Vl53l0x.h"
#include "Gy87_lib.h"
#include "hal/adc_types.h"
#include "hal/gpio_types.h"
#include "portmacro.h"
#include "soc/gpio_num.h"

// PINS
#define SDA_PIN               GPIO_NUM_3
#define SCL_PIN               GPIO_NUM_2
#define PWM_LEFT_PIN          GPIO_NUM_5
#define PWM_RIGHT_PIN         GPIO_NUM_4
#define BATTERY_MONITOR_PIN   GPIO_NUM_10
const gpio_num_t TOF_XSHUT_PIN[5] = {
  GPIO_NUM_8,
  GPIO_NUM_9,
  GPIO_NUM_11,
  GPIO_NUM_6,
  GPIO_NUM_7
};

// RTOS Tasks delay time
#define RTOS_TOF_TASK_INTERVAL_MS              150
#define RTOS_IMU_TASK_INTERVAL_MS              150
#define RTOS_BATTERY_MONITOR_TASK_INTERVAL_MS  150
#define RTOS_PWM_TASK_INTERVAL_MS              150

// Constants
#define ADC_TO_BATTERY_2S 3.3/4096*(10000+6200)/6200

// --------------------------------------------
// Hardware-relevant variables
const esp_partition_t *partition;
adc_oneshot_unit_handle_t adc_handler; 
SemaphoreHandle_t i2c_mutex;

Gy87 imu(true, false, true);
Vl53l0x tof[5];
float battery_voltage;

//------------- RTOS TASKS --------------------------
void imu_task(void*){
  if(not xSemaphoreTake(i2c_mutex, portMAX_DELAY)) while(true);
  // I2C shared-bus protection
  imu.init_i2c(I2C_NUM_0);
  imu.init_flash(partition);
  imu.config(
    DLPF_ACC_44HZ_GYRO_42HZ,
    ACC_AFS_SEL_4G,
    GYRO_FS_SEL_250_DEG_PER_SEC,
    MAG_SAMPLES_AVERAGED_1,
    MAG_DATA_OUTPUT_RATE_75_HZ,
    MAG_FIELD_RANGE_1P3_GA,
    MAG_MODE_CONTINUOUS_MEASUREMENT
  );
  // I2C shared-bus protection
  xSemaphoreGive(i2c_mutex);

  while(true){
    if(not xSemaphoreTake(i2c_mutex, portMAX_DELAY)) continue;

    xSemaphoreGive(i2c_mutex);
    vTaskDelay(pdMS_TO_TICKS(RTOS_IMU_TASK_INTERVAL_MS));
  }
}

void tof_task(void*){
  if(not xSemaphoreTake(i2c_mutex, portMAX_DELAY)) while(true) vTaskDelay(pdMS_TO_TICKS(1));
  // I2C shared-bus protection
  for(int i = 0; i < 5; i++) gpio_set_level(TOF_XSHUT_PIN[i], 0);
  for(int i = 0; i < 5; i++){
    gpio_set_level(TOF_XSHUT_PIN[i], 1);
    tof[i].setTimeout(500);
    tof[i].init(I2C_NUM_0);
    tof[i].setAddress(I2C_VL53L0X_ADDR + i);
    tof[i].setMeasurementTimingBudget(200000);
    gpio_set_level(TOF_XSHUT_PIN[i], 0);
  }
  // I2C shared-bus protection
  xSemaphoreGive(i2c_mutex);

  while(true){
    if(not xSemaphoreTake(i2c_mutex, portMAX_DELAY)) continue;

    xSemaphoreGive(i2c_mutex);
    vTaskDelay(pdMS_TO_TICKS(RTOS_BATTERY_MONITOR_TASK_INTERVAL_MS));
  }
}

void battery_monitor_task(void*){
  int adc_reading;
  while(true){
    adc_oneshot_read(adc_handler, ADC_CHANNEL_9, &adc_reading);
    battery_voltage = adc_reading * ADC_TO_BATTERY_2S;
    printf("%.4f\n", battery_voltage);
    vTaskDelay(pdMS_TO_TICKS(RTOS_BATTERY_MONITOR_TASK_INTERVAL_MS));
  }
}

void pwm_task(void*){
  while(true){
    vTaskDelay(pdMS_TO_TICKS(RTOS_PWM_TASK_INTERVAL_MS));
  }
}

//------------- FUNCS --------------------------
void i2c_scan(){
  esp_err_t res;
  printf("     0  1  2  3  4  5  6  7  8  9  a  b  c  d  e  f\n");
  printf("00:         ");
  for (uint8_t i = 3; i < 0x78; i++){
    i2c_cmd_handle_t cmd = i2c_cmd_link_create();
    i2c_master_start(cmd);
    i2c_master_write_byte(cmd, (i << 1) | I2C_MASTER_WRITE, 1 /* expect ack */);
    i2c_master_stop(cmd);

    res = i2c_master_cmd_begin(I2C_NUM_0, cmd, pdMS_TO_TICKS(10));
    if (i % 16 == 0) printf("\n%.2x:", i);
    if (res == 0) printf(" %.2x", i);
    else printf(" --");
    i2c_cmd_link_delete(cmd);
  }
  printf("\n\n");
  vTaskDelay(pdMS_TO_TICKS(1000));
}

extern "C" void app_main(void){
  // ----------- FLASH MEMORY INITIALIZATION ------------
  partition = esp_partition_find_first(ESP_PARTITION_TYPE_ANY, ESP_PARTITION_SUBTYPE_ANY, "calib"); 

  // ----------- I2C INITIALIZATION ------------
  i2c_config_t i2c_bus_config = {
    .mode = I2C_MODE_MASTER,
    .sda_io_num = SDA_PIN,
    .scl_io_num = SCL_PIN,
    .sda_pullup_en = GPIO_PULLUP_ENABLE,
    .scl_pullup_en = GPIO_PULLUP_ENABLE,
    .master = {
      .clk_speed = 100000
    },
    .clk_flags = I2C_SCLK_SRC_FLAG_FOR_NOMAL
  };
  i2c_param_config(I2C_NUM_0, &i2c_bus_config);
  i2c_driver_install(I2C_NUM_0, I2C_MODE_MASTER, 0, 0, 0);

  // ---------- GPIOS INITIALIZATION -----------------------
  for(int i = 0; i < 5; i++)
    gpio_set_direction(TOF_XSHUT_PIN[i], GPIO_MODE_OUTPUT);

  // ---------- ADC INITIALIZATION ----------------------
  // adc1, channel9 -> gpio10
  adc_oneshot_unit_init_cfg_t adc_config = {
    .unit_id = ADC_UNIT_1,
    .clk_src = ADC_RTC_CLK_SRC_DEFAULT,
    .ulp_mode = ADC_ULP_MODE_DISABLE
  };
  adc_oneshot_chan_cfg_t adc_channel_config = {
    .atten = ADC_ATTEN_DB_12,
    .bitwidth = ADC_BITWIDTH_12
  };
  adc_oneshot_new_unit(&adc_config, &adc_handler);
  adc_oneshot_config_channel(adc_handler, ADC_CHANNEL_9, &adc_channel_config);

  // ---------- SHARED RESOURCES PROTECTION AND INTER-TASK DATA EXCHANGE -----------------
  i2c_mutex = xSemaphoreCreateMutex();

  // ----------- TASKS ------------
  xTaskCreatePinnedToCore(imu_task, "imu task", 4096, NULL, 0, NULL, tskNO_AFFINITY);
  xTaskCreatePinnedToCore(tof_task, "tof task", 4096, NULL, 0, NULL, tskNO_AFFINITY);
  xTaskCreatePinnedToCore(battery_monitor_task, "battery monitoring task", 4096, NULL, 0, NULL, tskNO_AFFINITY);
  xTaskCreatePinnedToCore(pwm_task, "pwm task", 4096, NULL, 0, NULL, tskNO_AFFINITY);
}

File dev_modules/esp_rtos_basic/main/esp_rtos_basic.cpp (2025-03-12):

#include <stdio.h>
#include "esp_adc/adc_oneshot.h"
#include "freertos/FreeRTOS.h"
#include "freertos/task.h"
#include "freertos/queue.h"
#include "driver/gpio.h"
#include "esp_timer.h"

enum {
  BT_L_LEFT = (int)GPIO_NUM_46,
  BT_L_UP = (int)GPIO_NUM_7,
  BT_L_RIGHT = (int)GPIO_NUM_9,
  BT_L_DOWN = (int)GPIO_NUM_14,
  BT_L_CORNER = (int)GPIO_NUM_8,
  BT_R_LEFT = (int)GPIO_NUM_45,
  BT_R_UP = (int)GPIO_NUM_42,
  BT_R_RIGHT = (int)GPIO_NUM_48,
  BT_R_DOWN = (int)GPIO_NUM_47,
  BT_R_CORNER = (int)GPIO_NUM_2,
  BT_C_UP = (int)GPIO_NUM_3,
  BT_C_DOWN = (int)GPIO_NUM_39,
} button_ios;

#define GPIO_INPUT_PIN_SEL 1ULL << BT_L_LEFT | 1ULL << BT_L_UP | 1ULL << BT_L_RIGHT | 1ULL << BT_L_DOWN | 1ULL << BT_L_CORNER | \
                           1ULL << BT_R_LEFT | 1ULL << BT_R_UP | 1ULL << BT_R_RIGHT | 1ULL << BT_R_DOWN | 1ULL << BT_R_CORNER | \
                           1ULL << BT_C_UP | 1ULL << BT_C_DOWN

#define BUTTON_TIMING_CONSTRAINT_US 1000 // get rid of multiple rise/fall edge in single press/release

static QueueHandle_t gpio_evt_queue = NULL;
uint64_t last_rise_edge_time[49] = {0}, last_fall_edge_time[49] = {0};

void left_adc_task(void *arg){
  adc_oneshot_unit_handle_t x_adc_handler, y_adc_handler;
  adc_oneshot_unit_init_cfg_t
    x_adc_config = {
      .unit_id = ADC_UNIT_1,
      .clk_src = ADC_RTC_CLK_SRC_DEFAULT,
      .ulp_mode = ADC_ULP_MODE_DISABLE,
    },
    y_adc_config = {
      .unit_id = ADC_UNIT_1,
      .clk_src = ADC_RTC_CLK_SRC_DEFAULT,
      .ulp_mode = ADC_ULP_MODE_DISABLE,
    };
  adc_oneshot_new_unit(&x_adc_config, &x_adc_handler);
  adc_oneshot_new_unit(&y_adc_config, &y_adc_handler);

  adc_oneshot_chan_cfg_t channel_config = {
    .atten = ADC_ATTEN_DB_12,
    .bitwidth = ADC_BITWIDTH_12,
  };
  adc_oneshot_config_channel(x_adc_handler, ADC_CHANNEL_4, &channel_config); //GPIO5
  adc_oneshot_config_channel(y_adc_handler, ADC_CHANNEL_5, &channel_config); //GPIO6
  
  int adc_x, adc_y;
  while(true){
    // printf("hi: task 0 on core %d\n", esp_cpu_get_core_id());
    adc_oneshot_read(x_adc_handler, ADC_CHANNEL_4, &adc_x);
    adc_oneshot_read(y_adc_handler, ADC_CHANNEL_5, &adc_y);
    printf("%d %d\n", adc_x, adc_y);
    vTaskDelay(pdMS_TO_TICKS(100));
  }
  vTaskDelete(NULL);
}

static void IRAM_ATTR gpio_isr_handler(void* arg) {
  uint32_t io_num = (uint32_t) arg;
  xQueueSendFromISR(gpio_evt_queue, &io_num, NULL);
}

void button_task(void *arg){
  gpio_config_t io_conf = {
    .pin_bit_mask = GPIO_INPUT_PIN_SEL,
    .mode = GPIO_MODE_INPUT,
    .pull_up_en = GPIO_PULLUP_ENABLE,
    .pull_down_en = GPIO_PULLDOWN_DISABLE,
    .intr_type = GPIO_INTR_ANYEDGE
  };
  gpio_config(&io_conf);

  gpio_evt_queue = xQueueCreate(10, sizeof(uint32_t));
  gpio_install_isr_service(ESP_INTR_FLAG_LEVEL1);

  gpio_isr_handler_add(GPIO_NUM_7, gpio_isr_handler, (void*)7);
  gpio_isr_handler_add(GPIO_NUM_9, gpio_isr_handler, (void*)9);
  gpio_isr_handler_add(GPIO_NUM_14, gpio_isr_handler, (void*)14);
  gpio_isr_handler_add(GPIO_NUM_46, gpio_isr_handler, (void*)46);
  gpio_isr_handler_add(GPIO_NUM_42, gpio_isr_handler, (void*)42);
  gpio_isr_handler_add(GPIO_NUM_45, gpio_isr_handler, (void*)45);
  gpio_isr_handler_add(GPIO_NUM_48, gpio_isr_handler, (void*)48);
  gpio_isr_handler_add(GPIO_NUM_47, gpio_isr_handler, (void*)47);
  gpio_isr_handler_add(GPIO_NUM_8, gpio_isr_handler, (void*)8);
  gpio_isr_handler_add(GPIO_NUM_3, gpio_isr_handler, (void*)3);
  gpio_isr_handler_add(GPIO_NUM_39, gpio_isr_handler, (void*)39);
  gpio_isr_handler_add(GPIO_NUM_2, gpio_isr_handler, (void*)2);

  gpio_num_t io_num;
  uint64_t *ptr;
  while(true)
    if(xQueueReceive(gpio_evt_queue, &io_num, portMAX_DELAY)){
      uint64_t current_time = esp_timer_get_time();
      ptr = gpio_get_level(io_num) ? last_rise_edge_time : last_fall_edge_time;
      if(current_time - *(ptr + io_num) > BUTTON_TIMING_CONSTRAINT_US){
        *(ptr + io_num) = current_time;
        printf("GPIO[%d]\n", io_num);
      }
      // if(gpio_get_level(io_num)){ //rise edge
      //   if(current_time - last_rise_edge_time[io_num] > BUTTON_TIMING_CONSTRAINT_US){
      //     last_rise_edge_time[io_num] = current_time;
      //     // event execution
      //     printf("GPIO[%d] intr, val: 1\n", io_num);
      //   }
      // }else{ //fall edge
      //   if(current_time - last_fall_edge_time[io_num] > BUTTON_TIMING_CONSTRAINT_US){
      //     last_fall_edge_time[io_num] = current_time;
      //     // event execution
      //     printf("GPIO[%d] intr, val: 0\n", io_num);
      //   }
      // }
    }
  vTaskDelete(NULL);
}

extern "C" void app_main(void){
  // xTaskCreatePinnedToCore(left_adc_task, "Left ADC task", 4096, NULL, 0, NULL, tskNO_AFFINITY);
  xTaskCreatePinnedToCore(button_task, "Button task", 4096, NULL, 0, NULL, tskNO_AFFINITY);
  return;
}

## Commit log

2025-01-04 pwm done
2025-01-04 adc and led rgb done
2025-01-04 [Add] file system and some functions
    [partitions.csv]
2025-01-07 esp gamepad pcb done
    [esp_gamepad.kicad_pcb, esp_gamepad.kicad_sch, partitions.csv]
2025-01-09 gamepad done
    [bom.csv, esp_gamepad.kicad_pcb, esp_gamepad.kicad_sch]
2025-01-10 3d model
    [esp_gamepad.kicad_pcb]
2025-01-12 pcb modification
    [esp_gamepad-B_Cu.gbr, esp_gamepad-B_Mask.gbr, esp_gamepad-B_Paste.gbr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]
2025-01-13 partition flash done
    [partitions.csv]
2025-01-14 tof sensor 50percent
2025-01-17 downgrade i2c version mpu6050
2025-01-17 vl53l0x i2c interface partially done
2025-01-18 mpu6050 partition api 90% done
    [partitions.csv]
2025-01-20 mpu6050 partition api fixed
    [partitions.csv]
2025-01-23 gamepad v2 done
    [esp_gamepad.kicad_pcb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]
2025-02-09 pcb foorprint bug fixing
    [esp_gamepad_v2.kicad_pcb, esp_gamepad_v2.kicad_sch]
2025-02-28 add motors and driver
    [micromouse.kicad_sch]
2025-03-04 100% done
    [micromouse.kicad_pcb, micromouse.kicad_sch]
2025-03-07 pcb gerbers done
    [micromouse-B_Cu.gbr, micromouse-B_Mask.gbr, micromouse-B_Paste.gbr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]
2025-03-12 3d model and pcb micromouse done
    [GA12_N20_Bracket.step, GA12_N20_Motor.step, keycap_lowprofile.step]
2025-03-12 remove unnecessary files
    [GA12_N20_Bracket.step, GA12_N20_Motor.step, keycap_lowprofile.step]
2025-03-18 [Initialize] uart_communication,neural_network dev-modules
2025-04-08 main controller creation
    [partitions.csv]
2025-04-08 main_controller dev
    [bom.csv]
2025-04-08 mutex i2c protection
